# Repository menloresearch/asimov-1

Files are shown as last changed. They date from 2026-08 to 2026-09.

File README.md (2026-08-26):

# Asimov 1: Open-Source Humanoid Robot




Asimov is an open-source humanoid robot that you can build, train and customize.

Asimov v1
<p align="center">
  <a href="https://asimov.inc">Website</a> ·
  <a href="https://manual.asimov.inc">Manual</a> ·
  <a href="https://asimov.inc/diy-kit">DIY Kit</a> ·
  <a href="https://static.asimov.inc/asimov/v1/asimov-v1-20260420.html">3D Model</a> ·
  <a href="https://discord.gg/HzDfGN7kUw">Discord</a> ·
  <a href="https://x.com/asimovinc">X</a> ·
  <a href="https://forum.menlo.ai">Forum</a>
</p>

Asimov 1 is a 1.2 m, 35 kg biped with 25 actuated degrees of freedom. This repository contains the mechanical CAD, electrical CAD, simulation model, and onboard software to build, simulate, and customize Asimov 1.

---

## Specifications

| Spec | Value |
|---|---|
| Height | 1.2 m |
| Weight | 35 kg |
| Degrees of Freedom | 25 actuated |
| Legs | 6 DOF x 2 |
| Arms | 5 DOF x 2 (shoulder pitch/roll/yaw, elbow, wrist yaw) |
| Torso | 1 DOF waist yaw, 10 W 4 ohm speaker, 6 DOF IMU |
| Head | 2 DOF neck (neck yaw, neck pitch), stereo microphone array, 2MP monocular camera |
| CAN Bus | 5 @ 1Mbps + 1 @ 500kbps |
| Onboard Compute | Raspberry Pi 5 (media + network) + Radxa CM5 (motion control) |
| Structural Materials | 7075 aluminium, MJF PA12 nylon |

| Activity | Load |
|---|---|
| Squat | 5 kg |
| Bicep curl | 15 kg each arm |
| Lateral raise | 18 kg each arm |

---

## Build your own Asimov

> [!TIP]
> **Option 1: DIY Kit:** Everything you need to build Asimov 1, unassembled. Shipping now for $20,000. [Order now →](https://menlo.ai/asimov-1#buy)

> [!NOTE]
> **Option 2: Self-source:** Pull the [BOM](https://docs.menlo.ai/asimov/1/assembly-preparations/self-source/select-release-and-bom) and fabricate everything yourself. [Assembly Manual →](https://docs.menlo.ai/asimov/1)

### DIY Kit

| Category | Included | Not Included |
|---|---|---|
| Hardware | All BOM components (unassembled), power supply & cabling, spare parts | Tools, hands |
| Compute | RPi edge board, motion control board, network board, power distribution board | 4G/5G modules |
| Sensors | Monocular camera, IMUs, mic, speaker, motor joint states | Lidar, 360 cam |
| Docs | Quick start guide, manual, DIY build videos | — |

**[Pre-order the Asimov 1 DIY Kit →](https://asimov.inc/diy-kit)**

### Self-source

Start with the repo-local [fabrication manifest](mechanical/FABRICATION_MANIFEST.csv) for the CAD-derived part inventory, then cross-reference the [BOM](https://manual.asimov.inc/v1/bom) and assembly manual for procurement details, sourcing, and fabrication notes.

**[Assembly Manual →](https://manual.asimov.inc)**

---

## Fabrication manifest

The CAD-derived fabrication manifest can be checked locally:

```bash
python3 scripts/generate_fabrication_manifest.py --check
```

---

## Roadmap

| Status | Item |
|---|---|
| ✅ | Mechanical CAD — 7 subassemblies |
| ✅ | MuJoCo simulation model |
| ✅ | Electrical wiring harness |
| ✅ | Electrical schematics & PCB files |
| 🔜 | Asimov Edge |
| 🔜 | Locomotion policy |

---

## Work with us

- **Build questions?**: Ask in the [forum](https://forum.menlo.ai) or open a [GitHub Issue](https://github.com/asimovinc/asimov-v1/issues) for bugs and contributions.
- **Deploying Asimov?**: [Talk to us →](mailto:bd@menlo.ai)
- **Supply chain partner?**: If you manufacture actuators, structural components, or electronics and want to be part of the Asimov supply chain, reach out.
[bd@menlo.ai](mailto:bd@menlo.ai)

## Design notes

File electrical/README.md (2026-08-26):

## Robot Processing Unit 
### Motion Control Board
- The Motion Control Board (MCB) is a carrier board designed for the Radxa CM5. It has an onboard IMU and contains the necessary motor communication buses for the robot to function.
- The Power Distribution Board (PDB) sits on top of the Motion Control Board (MCB) to form the 2 board stackup.

General information:
- Power is supplied via the XT90(2+2) connector on the PDB, with 5V being routed to the MCB at the bottom
- The UART TTL debug lines have been fanned out as test pads on the PDB for debugging purposes.
- The LSM6DSV IMU is located at the bottom of the MCB
- LCSC component IDs are attached in the KiCad source files for direct JLCPCB fabrication and assembly.

### Communication Ports

| Port Type | Quantity | Details |
|---|---|---|
| CAN (SPI-CAN) | 6 | CAN via SPI bridge |
| USB 2.0 | 2 | USB interfaces |
| Ethernet | 1 | 1Gbps |
| I2C | 1 | I2C interface |

### Port Mapping

| Port ID | Purpose |
|---|---|
| LL | Left leg bus |
| RL | Right leg bus |
| LA | Left arm bus |
| RA | Right arm bus |
| NP | Neck pitch connection for the torso bus |
| NY | Neck yaw connection for the torso bus |
| W  | Waist yaw connection for the torso bus |

> Please refer to the KiCAD source files for a detailed view of all pin mappings on the PDB

## Media Unit

The head of the robot contains a RPI5, with 2 boards to support its function.

Head board:
- contains buck converters to power the RPI5 with 5V
- an audio IC to handle the stereo microphones and stereo speakers, although only 1 speaker output is currently used

RPI5 Hat:
- a small hat that allows for a clean 5V connection to the headers of the RPI5
- contains a button, LED and buzzer for basic status messages, similar to a consumer motherboard

## Wiring

- Each line refers to a pre-made cable on the robot
- Certain connections can only be complete post assembly due to space contraints. These connections have been marked with the Joint names WAGO or SOLDER.

> If making cables from scratch, double-check wire pathing to make sure there is sufficient slack on each connection.

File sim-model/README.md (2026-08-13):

# Simulation Model

MuJoCo model for Asimov v1. Floating base with 23 hinge joints, 25 STL link meshes, friction-tuned foot contacts. Built for locomotion policy training and hardware-in-the-loop testing. No actuators are defined in the XML — the training sim configures them in Python.

## Contents

```
sim-model/
├── xmls/asimov_1.xml     Full robot model (MJCF)
├── urdf/asimov_1.urdf    URDF description (shares the same meshes)
└── assets/meshes/        25 STL link meshes
```

## Usage

```bash
python3 -m mujoco.viewer --mjcf=sim-model/xmls/asimov_1.xml
```

Requires [MuJoCo](https://mujoco.org/) 3.x.

## Resources

- [Locomotion Control guide](https://manual.asimov.inc/v1/locomotion) — policy training, control modes, and hardware-in-the-loop setup
- [Asimov API](https://manual.asimov.inc/v1/api) — deploy policies to the real robot
- [Discord](https://discord.gg/HzDfGN7kUw) — questions and discussion

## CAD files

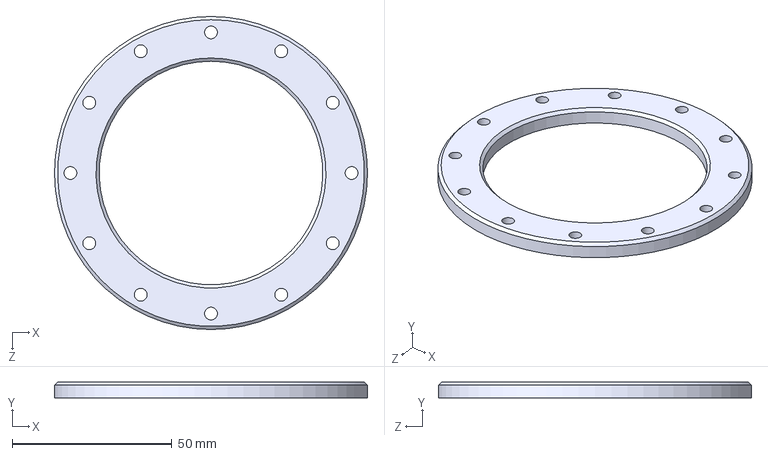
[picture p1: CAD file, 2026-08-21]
mechanical/ASV1/100/FABRICATION/ALU_7075/ASV1_100_08A.STEP
98.0 x 5.00 x 98.0 mm

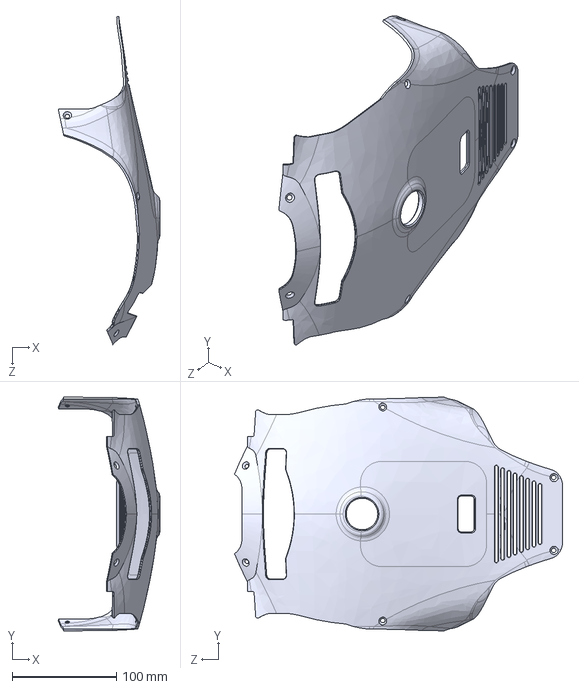
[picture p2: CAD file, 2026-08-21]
mechanical/ASV1/100/FABRICATION/MJF_PA12/ASV1_100_04C.STEP
97.5 x 224.3 x 314.8 mm

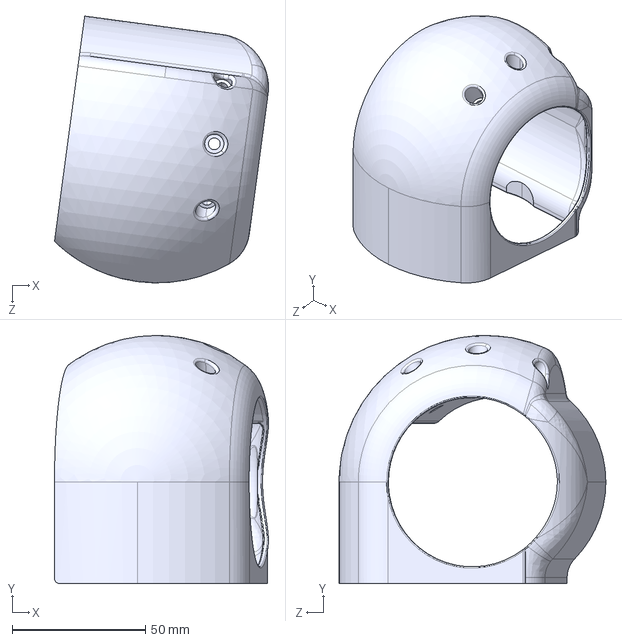
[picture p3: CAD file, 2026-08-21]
mechanical/ASV1/200/FABRICATION/MJF_PA12/ASV1_200_08C.STEP
80.2 x 92.9 x 100.0 mm

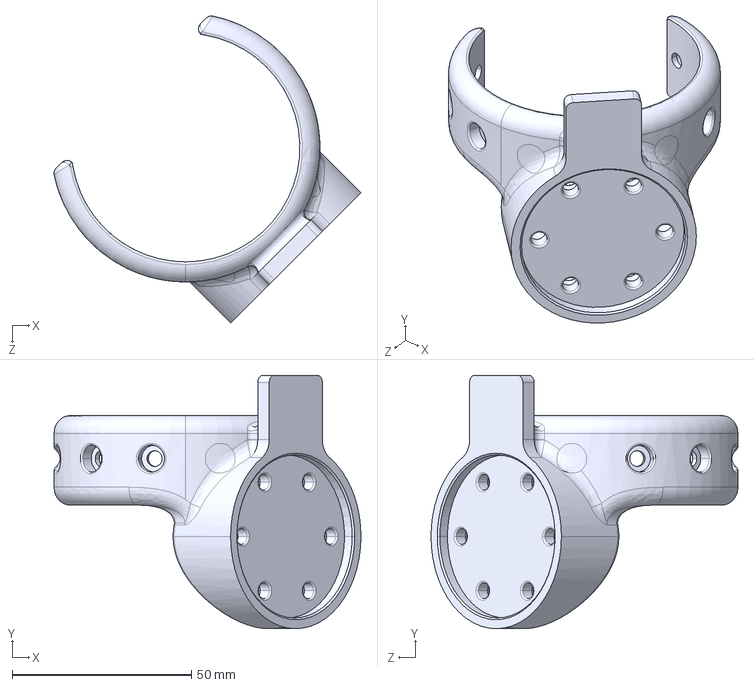
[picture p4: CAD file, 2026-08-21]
mechanical/ASV1/200/FABRICATION/SML_316L/ASV1_200_04B.STEP
85.7 x 70.7 x 85.7 mm

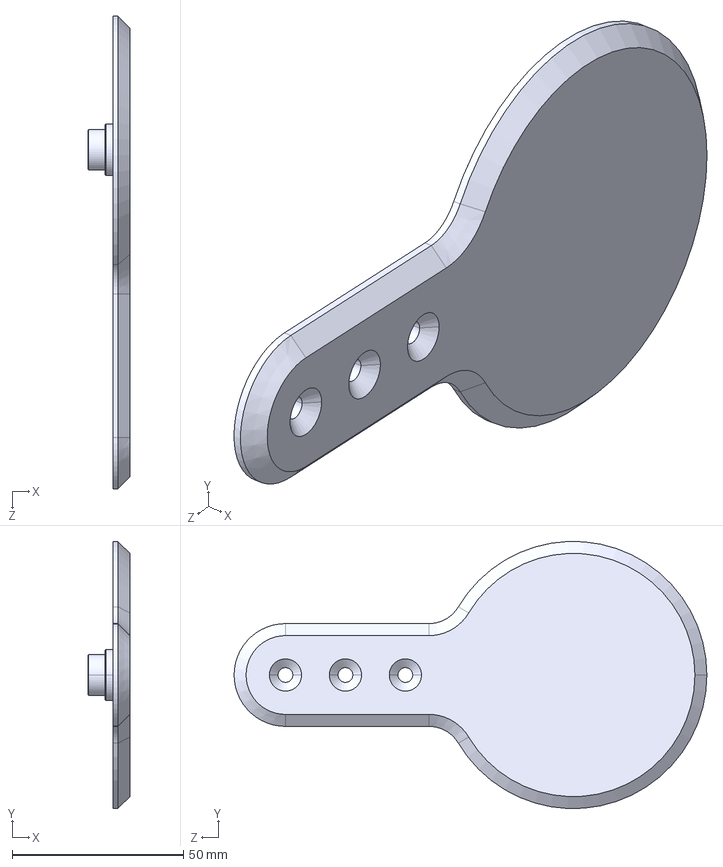
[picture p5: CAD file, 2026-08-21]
mechanical/ASV1/300/FABRICATION/ALU_7075/ASV1_300_10A.STEP
12.2 x 77.9 x 138.0 mm

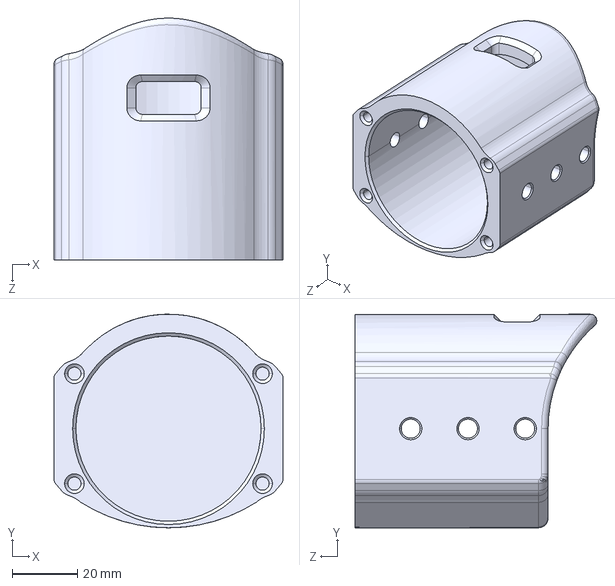
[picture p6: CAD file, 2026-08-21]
mechanical/ASV1/300/FABRICATION/MJF_PA12/ASV1_300_16C.STEP
70.0 x 65.3 x 73.9 mm

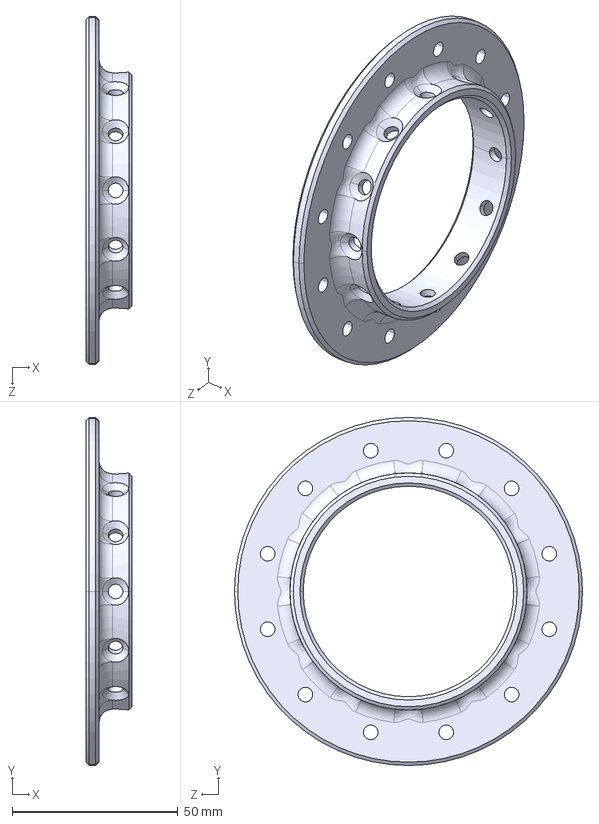
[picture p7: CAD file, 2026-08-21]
mechanical/ASV1/300/FABRICATION/SML_316L/ASV1_300_04B.STEP
14.0 x 105.0 x 105.0 mm

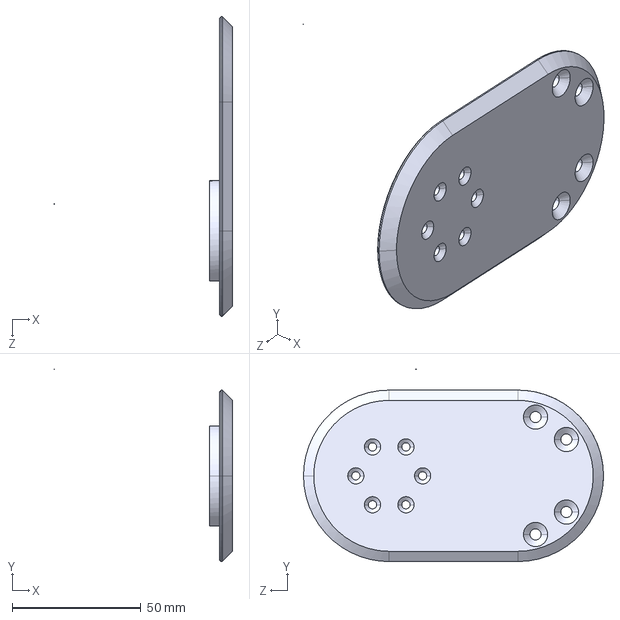
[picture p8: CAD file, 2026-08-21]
mechanical/ASV1/400/FABRICATION/ALU_7075/ASV1_400_01A.STEP
69.3 x 74.8 x 116.7 mm

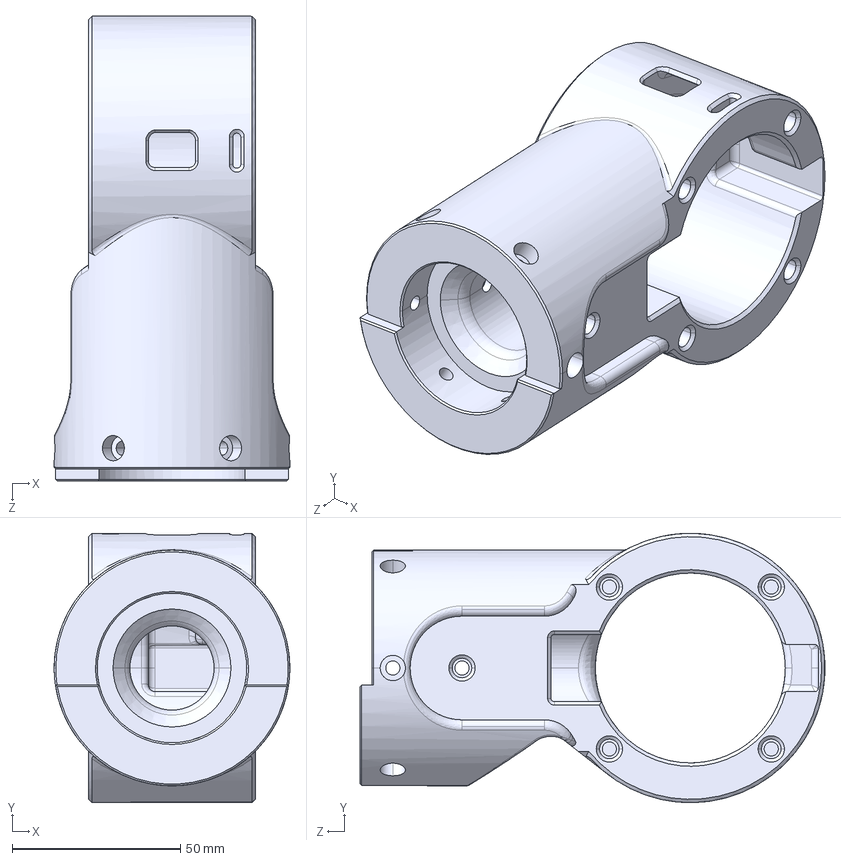
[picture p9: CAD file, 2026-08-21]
mechanical/ASV1/400/FABRICATION/MJF_PA12/ASV1_400_15C.step
70.0 x 80.0 x 138.1 mm

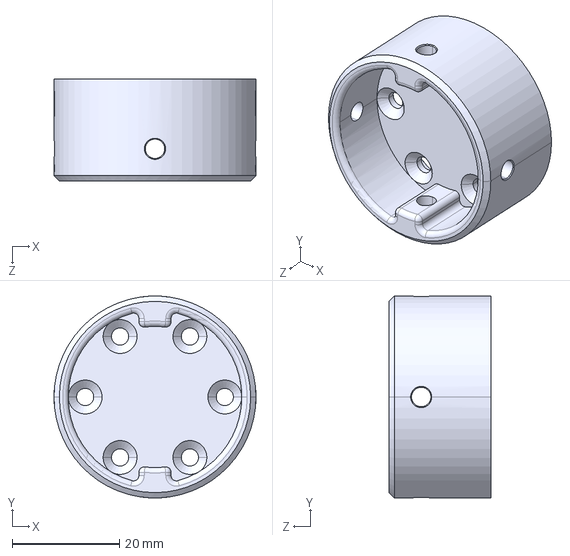
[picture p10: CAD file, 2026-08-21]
mechanical/ASV1/400/FABRICATION/SML_316L/ASV1_400_12B.STEP
37.6 x 37.6 x 19.0 mm

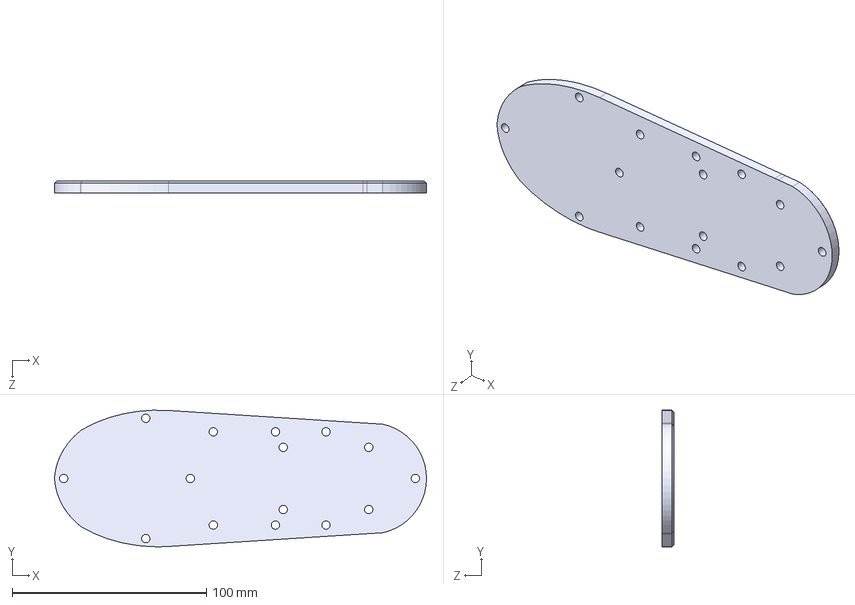
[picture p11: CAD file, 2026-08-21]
mechanical/ASV1/500/FABRICATION/ALU_7075/ASV1_500_36A.STEP
191.5 x 70.3 x 6.00 mm

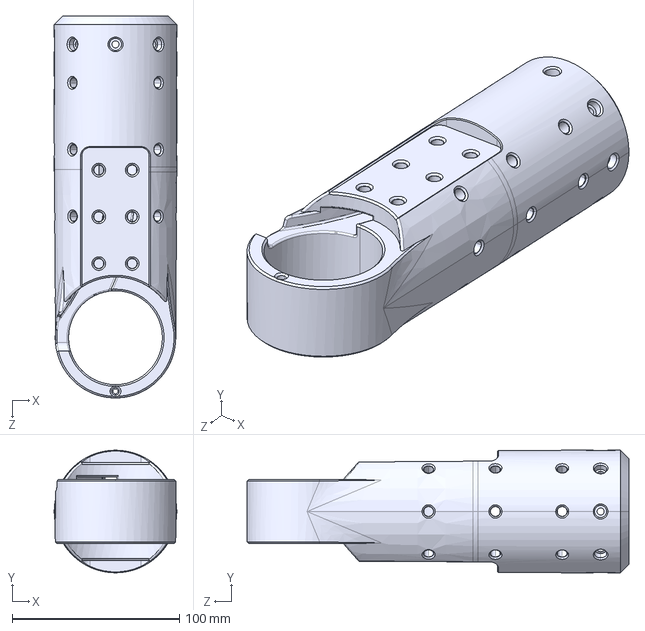
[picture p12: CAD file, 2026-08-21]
mechanical/ASV1/500/FABRICATION/MJF_PA12/ASV1_500_03C.STEP
73.4 x 73.4 x 228.7 mm

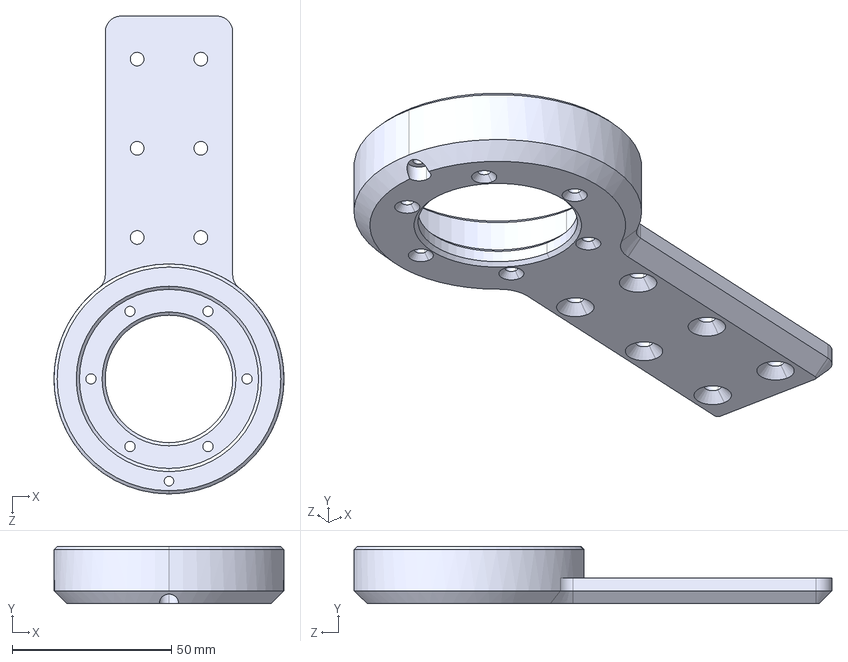
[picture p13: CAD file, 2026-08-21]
mechanical/ASV1/600/FABRICATION/ALU_7075/ASV1_600_06A.STEP
72.2 x 18.0 x 150.0 mm

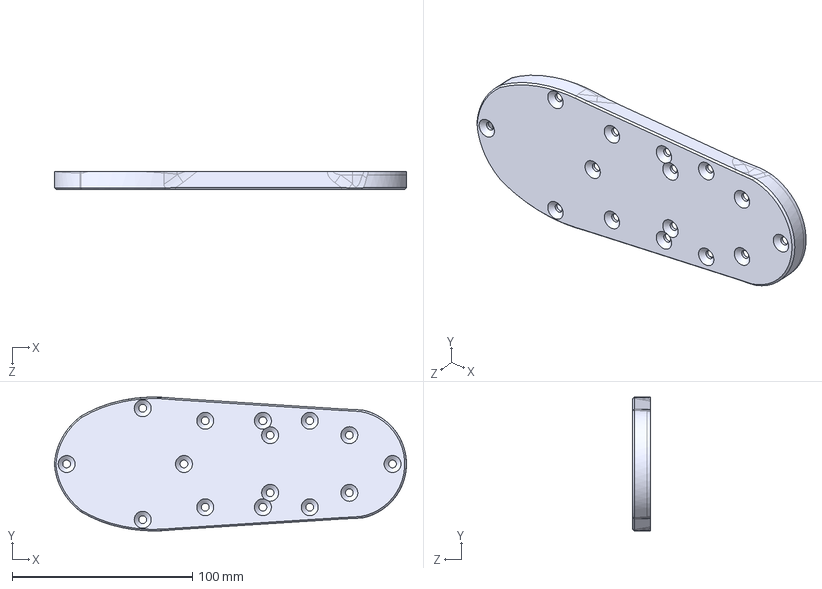
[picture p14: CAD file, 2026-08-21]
mechanical/ASV1/600/FABRICATION/MJF_PA12/ASV1_600_39C.STEP
195.5 x 74.4 x 10.0 mm

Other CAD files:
mechanical/ASV1/600/FABRICATION/SML_316L/ASV1_600_17B.STEP
mechanical/ASV1/700/FABRICATION/MJF_PA12/ASV1_700_06C.STEP
mechanical/ASV1/FullBodyAssembly/Asimov_1.STEP
sim-model/assets/meshes/ANKLE_B_NEW.STL
mechanical/ASV1/100/FABRICATION/MJF_PA12/ASV1_100_12C.STEP
mechanical/ASV1/100/FABRICATION/MJF_PA12/ASV1_100_16C.STEP
mechanical/ASV1/100/FABRICATION/OFF_THE_SHELF/ASV1_100_13X.STEP
mechanical/ASV1/100/FABRICATION/OFF_THE_SHELF/ASV1_100_14X.STEP
mechanical/ASV1/100/FABRICATION/OFF_THE_SHELF/ASV1_100_15X.STEP
mechanical/ASV1/100/FABRICATION/OFF_THE_SHELF/ASV1_100_16X.STEP
mechanical/ASV1/200/FABRICATION/MJF_PA12/ASV1_200_06C.STEP
mechanical/ASV1/200/FABRICATION/MJF_PA12/ASV1_200_15C.STEP
mechanical/ASV1/300/FABRICATION/ALU_7075/ASV1_300_01A.STEP
mechanical/ASV1/300/FABRICATION/ALU_7075/ASV1_300_02A.STEP
mechanical/ASV1/300/FABRICATION/ALU_7075/ASV1_300_03A.STEP
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

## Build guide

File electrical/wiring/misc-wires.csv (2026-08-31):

Joint_1 | Joint_2 | Length (mm) | End_1 | End_2 | Qty
RPU | RPI | 1000 | RJ45 Male | RJ45 Male | 1
RPU | Head Board | 1000 | XT30-F | XT30-M | 1
RPU | Fan | 100 | JST-XH 4 pin | SOLDER | 1
Head Board | RPI 5 Hat | 120 | JST-XH 4 pin | JST-XH 4 pin | 1
Head Board | RPI | 100 | USB-C | USB-A | 1
Head Board | WAGO | 100 | JST-XH 4 pin | N/A | 1
Speaker | WAGO | 200 | SOLDER | N/A | 1

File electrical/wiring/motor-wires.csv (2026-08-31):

Joint_1 | Joint_2 | Length (mm) | End_1 | End_2 | Qty
Left Shoulder Pitch | SOLDER | 180 | XT30F(2+2) | N/A | 1
Left Shoulder Roll | SOLDER | 100 | XT30F(2+2) | N/A | 1
Left Shoulder Roll | Left Shoulder Yaw | 100 | XT30F(2+2) | XT30F(2+2) | 1
Left Shoulder Yaw | WAGO | 180 | XT30F(2+2) | N/A | 1
Left Elbow | WAGO | 100 | XT30F(2+2) | N/A | 1
Left Elbow | Left Wrist Yaw | 230 | XT30F(2+2) | XT30F(2+2) | 1
Right Shoulder Pitch | SOLDER | 180 | XT30F(2+2) | N/A | 1
Right Shoulder Roll | SOLDER | 100 | XT30F(2+2) | N/A | 1
Right Shoulder Roll | Right Shoulder Yaw | 100 | XT30F(2+2) | XT30F(2+2) | 1
Right Shoulder Yaw | WAGO | 180 | XT30F(2+2) | N/A | 1
Right Elbow | WAGO | 100 | XT30F(2+2) | N/A | 1
Right Elbow | Right Wrist Yaw | 230 | XT30F(2+2) | XT30F(2+2) | 1
Left Hip Pitch | Left Hip Roll | 200 | XT30F(2+2) | XT30F(2+2) | 1
Left Hip Roll | SOLDER | 180 | XT30F(2+2) | N/A | 1
Left Hip Yaw | SOLDER | 280 | XT30F(2+2) | N/A | 1
Left Hip Yaw | Left Knee | 150 | XT30F(2+2) | XT30F(2+2) | 1
Left Knee | Left Ankle A | 100 | XT30F(2+2) | XT30F(2+2) | 1
Left Ankle A | Left Ankle B | 100 | XT30F(2+2) | XT30F(2+2) | 1
Right Hip Pitch | Right Hip Roll | 200 | XT30F(2+2) | XT30F(2+2) | 1
Right Hip Roll | SOLDER | 180 | XT30F(2+2) | N/A | 1
Right Hip Yaw | SOLDER | 280 | XT30F(2+2) | N/A | 1
Right Hip Yaw | Right Knee | 150 | XT30F(2+2) | XT30F(2+2) | 1
Right Knee | Right Ankle A | 100 | XT30F(2+2) | XT30F(2+2) | 1
Right Ankle A | Right Ankle B | 100 | XT30F(2+2) | XT30F(2+2) | 1
Neck Yaw | Neck Pitch | 200 | XT30F(2+2) | XT30F(2+2) | 1
RPU | Waist Yaw | 300 | XT30F(2+2) | XT30F(2+2) | 1
RPU | Left Hip Pitch | 300 | XT30F(2+2) | XT30F(2+2) | 1
RPU | Right Hip Pitch | 300 | XT30F(2+2) | XT30F(2+2) | 1
RPU | Left Shoulder Pitch | 400 | XT30F(2+2) | XT30F(2+2) | 1
RPU | Right Shoulder Pitch | 400 | XT30F(2+2) | XT30F(2+2) | 1
RPU | Neck Yaw | 600 | XT30F(2+2) | XT30F(2+2) | 1
RPU | Neck Pitch | 600 | XT30F(2+2) | XT30F(2+2) | 1

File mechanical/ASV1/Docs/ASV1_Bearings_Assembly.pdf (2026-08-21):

D

D

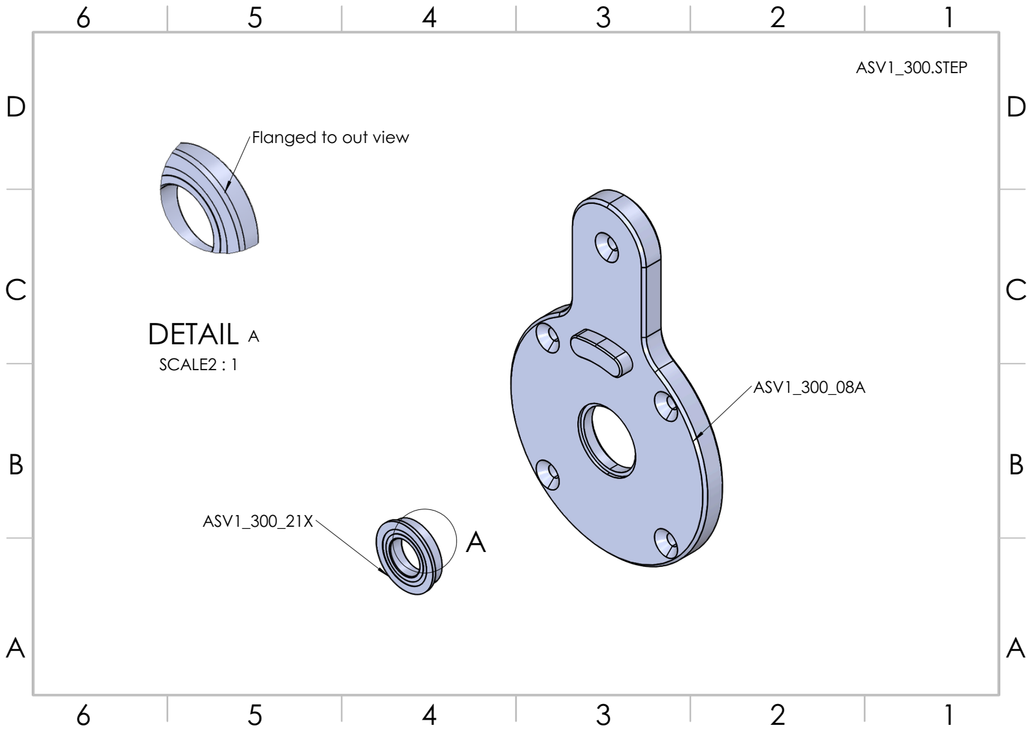
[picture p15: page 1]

# DETAIL

A

A
SCALE2 : 1

ASV1_300_21X

Flanged to out view

ASV1_300_08A

ASV1_300.STEP

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
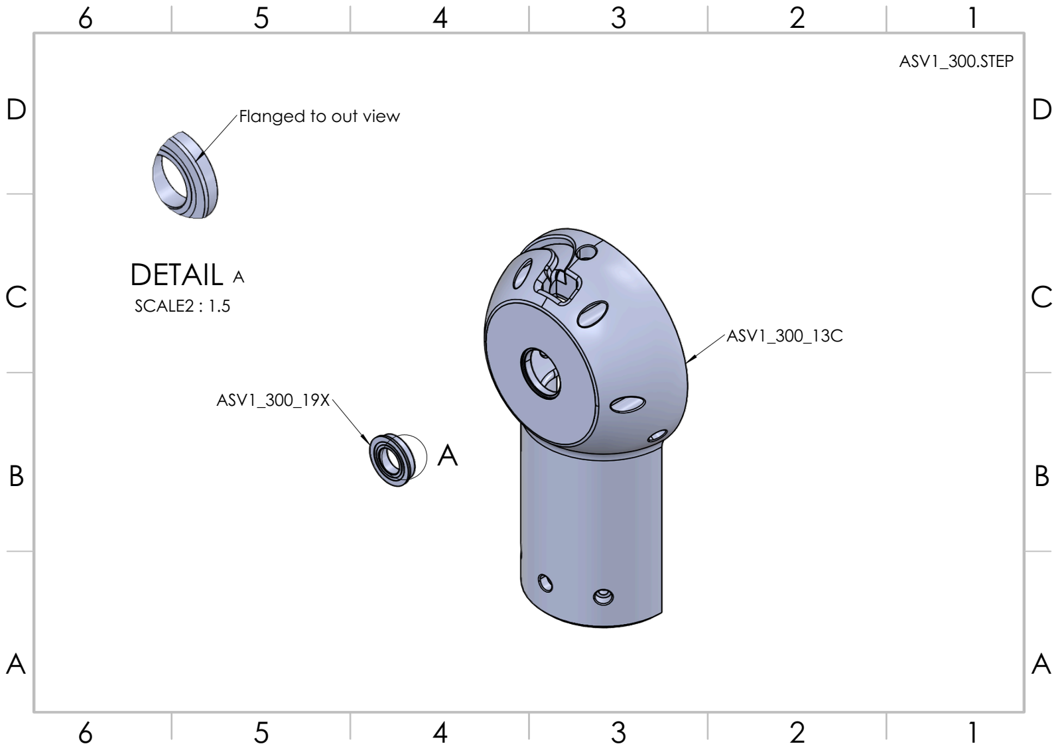
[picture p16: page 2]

# DETAIL

A

A
SCALE2 : 1.5

ASV1_300_19X

Flanged to out view

ASV1_300_13C

ASV1_300.STEP

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
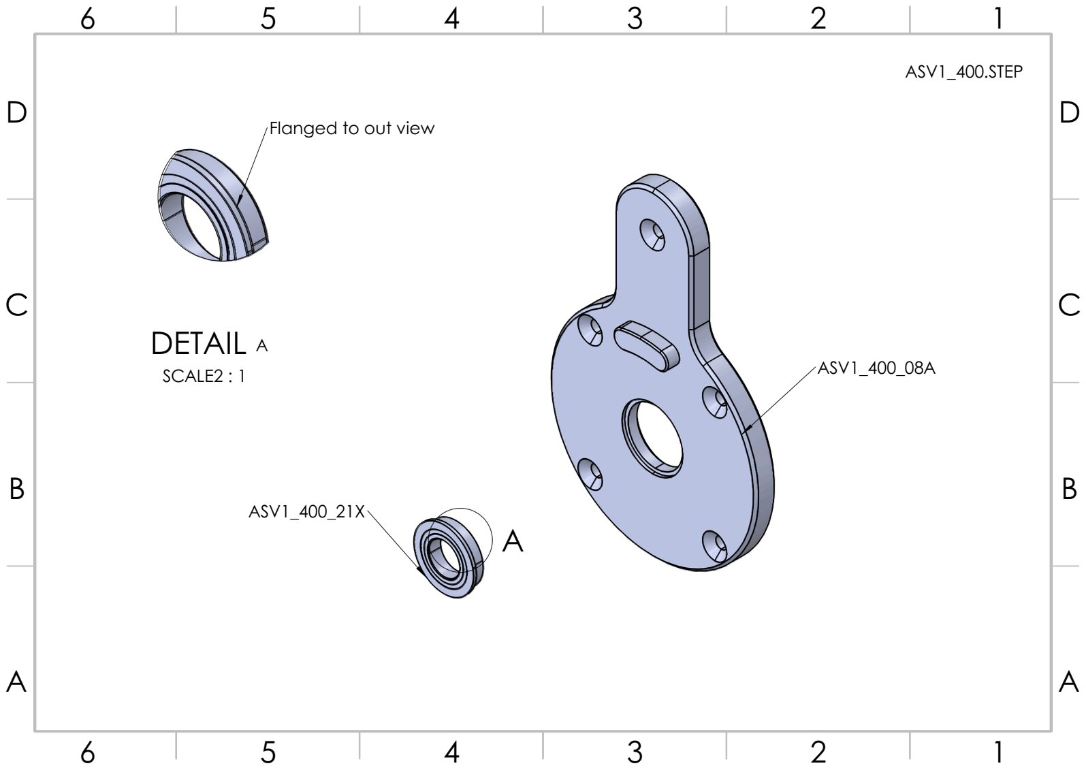
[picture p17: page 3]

# DETAIL

A

A
SCALE2 : 1

ASV1_400_21X

Flanged to out view

ASV1_400_08A

ASV1_400.STEP

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
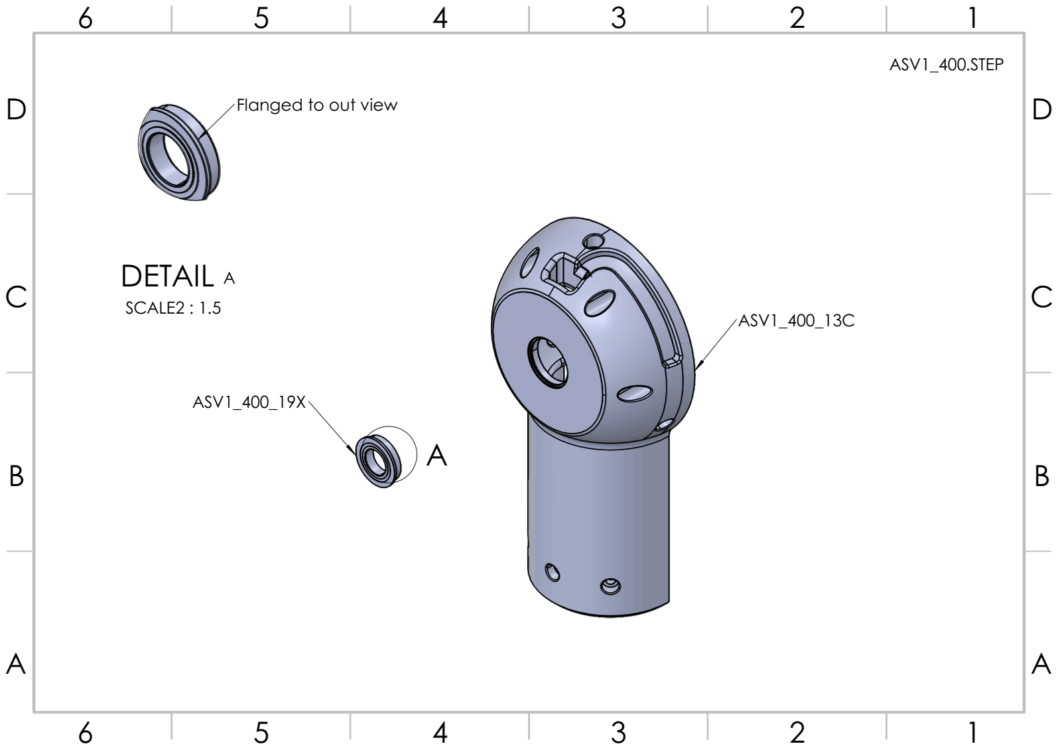
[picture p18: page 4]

# DETAIL

A

A
SCALE2 : 1.5

ASV1_400_19X

Flanged to out view

ASV1_400_13C

ASV1_400.STEP

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
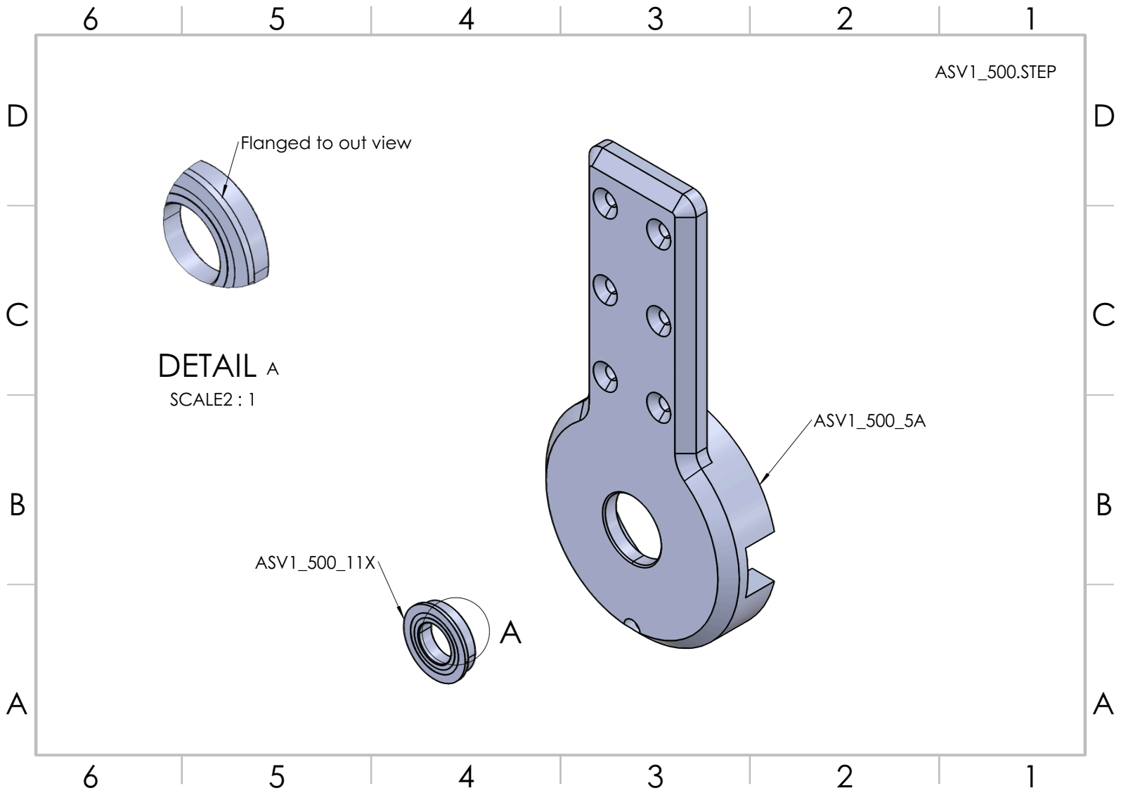
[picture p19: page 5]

# DETAIL

A

A
SCALE2 : 1

ASV1_500_11X

Flanged to out view

ASV1_500_5A

ASV1_500.STEP

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
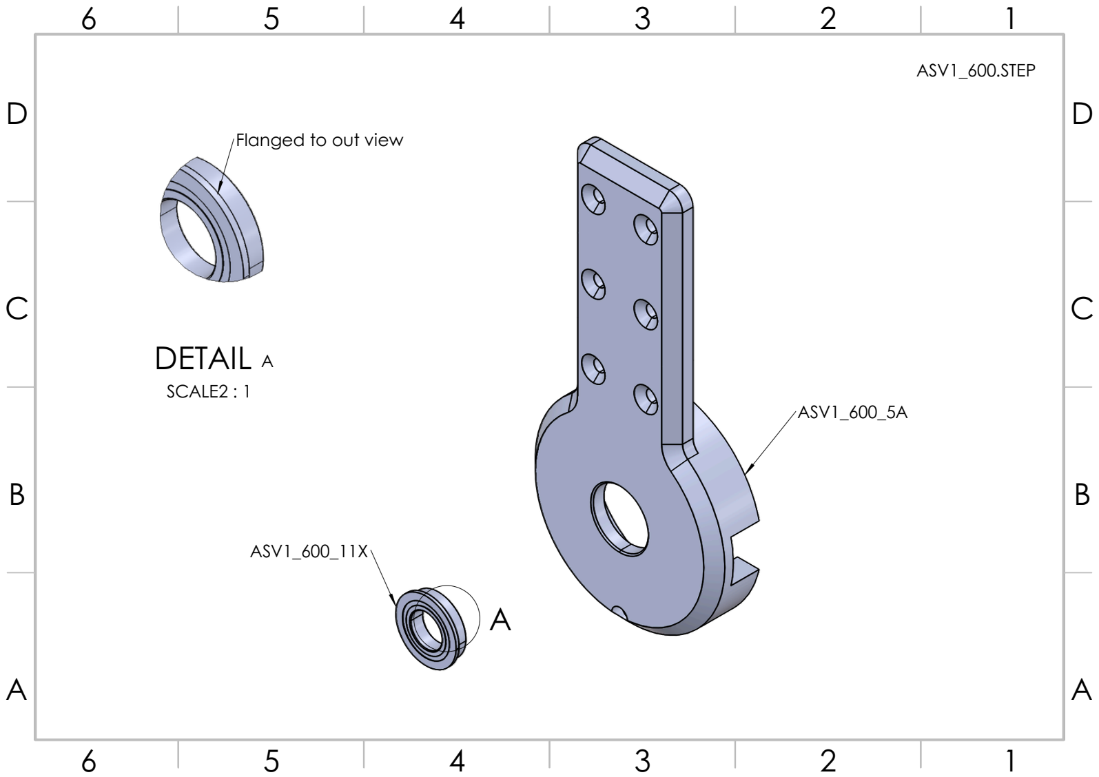
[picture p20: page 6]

# DETAIL

A

A
SCALE2 : 1

ASV1_600_11X

Flanged to out view

ASV1_600_5A

ASV1_600.STEP

C

A

B

C

A

B

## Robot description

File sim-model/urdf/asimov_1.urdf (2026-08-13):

<?xml version="1.0" ?>
<robot name="asimov_1">
  <link name="pelvis_link">
    <inertial>
      <origin xyz="-0.05409183232 -3.482595224e-05 -0.01562551822" rpy="0.1586136416 0.0003031020631 1.564644489"/>
      <mass value="3.506912512"/>
      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
    </inertial>
    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
  </link>
  <link name="left_hip_pitch_link">
    <inertial>
      <origin xyz="0.001728954335 0.03605632625 0.0005692667395" rpy="1.641985992 -0.155733979 1.833607493"/>
      <mass value="1.056301122"/>
      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
    </inertial>
    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
  </link>
  <joint name="left_hip_pitch_joint" type="revolute">
    <origin xyz="-0.052 0.0675 -0.044045" rpy="0 0 0"/>
    <parent link="pelvis_link"/>
    <child link="left_hip_pitch_link"/>
    <axis xyz="0 1 0"/>
    <limit lower="-2.094395" upper="1" effort="45" velocity="12.57"/>
  </joint>
  <link name="left_hip_roll_link">
    <inertial>
      <origin xyz="-0.01155413907 -0.0003348279462 -0.02941018527" rpy="-0.01180745454 0.7190823005 -0.04298463393"/>
      <mass value="0.4143681394"/>
      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
    </inertial>
    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
  </link>
  <joint name="left_hip_roll_joint" type="revolute">
    <origin xyz="0.0422501 0.04000027594 0" rpy="0 0 0"/>
    <parent link="left_hip_pitch_link"/>
    <child link="left_hip_roll_link"/>
    <axis xyz="1 0 0"/>
    <limit lower="-0.785398" upper="0.785398" effort="45" velocity="3.98"/>
  </joint>
  <link name="left_hip_yaw_link">
    <inertial>
      <origin xyz="0.00107948197 -0.00598402495 -0.1208133804" rpy="-0.0179107442 0.05361938077 1.506456195"/>
      <mass value="1.866570164"/>
      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
    </inertial>
    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
  </link>
  <joint name="left_hip_yaw_joint" type="revolute">
    <origin xyz="-0.04225 0.00700892571 -0.05152547875" rpy="0 0 0"/>
    <parent link="left_hip_roll_link"/>
    <child link="left_hip_yaw_link"/>
    <axis xyz="0 0 -1"/>
    <limit lower="-0.785398" upper="0.785398" effort="28" velocity="5.45"/>
  </joint>
  <link name="left_knee_link">
    <inertial>
      <origin xyz="-0.002016493104 7.425481682e-05 -0.09037473617" rpy="0.08663120203 0.01290091604 1.434104957"/>
      <mass value="2.391141511"/>
      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
    </inertial>
    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
  </link>
  <joint name="left_knee_joint" type="revolute">
    <origin xyz="0.001515728659 -0.006573890992 -0.218432673" rpy="0 0 0"/>
    <parent link="left_hip_yaw_link"/>
    <child link="left_knee_link"/>
    <axis xyz="0 1 0"/>
    <limit lower="0" upper="1.5" effort="45" velocity="12.25"/>
  </joint>
  <link name="left_ankle_pitch_link">
    <inertial>
      <origin xyz="-0.001179270406 -3.070191135e-08 -0.006176192354" rpy="0.06265384317 6.376502021e-06 1.570810298"/>
      <mass value="0.2730901194"/>
      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
    </inertial>
    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
  </link>
  <joint name="left_ankle_pitch_joint" type="revolute">
    <origin xyz="-0.001515728659 -0.0004350347189 -0.2723441844" rpy="0 0 0"/>
    <parent link="left_knee_link"/>
    <child link="left_ankle_pitch_link"/>
    <axis xyz="0 1 0"/>
    <limit lower="-0.35" upper="0.35" effort="40" velocity="9.32"/>
  </joint>
  <link name="left_ankle_roll_link">
    <inertial>
      <origin xyz="0.0602 0 -0.0174" rpy="0.005104327522 -1.544931719 3.136469831"/>
      <mass value="0.44468"/>
      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
    </inertial>
    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
  </link>
  <joint name="left_ankle_roll_joint" type="revolute">
    <origin xyz="-0.0015 0 -0.01" rpy="0 0 0"/>
    <parent link="left_ankle_pitch_link"/>
    <child link="left_ankle_roll_link"/>
    <axis xyz="-1 0 0"/>
    <limit lower="-0.1" upper="0.1" effort="17" velocity="9.32"/>
  </joint>
  <link name="right_hip_pitch_link">
    <inertial>
      <origin xyz="0.00172891544 -0.03605607775 0.0005688308451" rpy="1.642012672 0.1558053402 1.307990399"/>
      <mass value="1.056297429"/>
      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
    </inertial>
    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
  </link>
  <joint name="right_hip_pitch_joint" type="revolute">
    <origin xyz="-0.052 -0.0675 -0.044045" rpy="0 0 0"/>
    <parent link="pelvis_link"/>
    <child link="right_hip_pitch_link"/>
    <axis xyz="0 -1 0"/>
    <limit lower="-1" upper="2.094395" effort="45" velocity="12.57"/>
  </joint>
  <link name="right_hip_roll_link">
    <inertial>
      <origin xyz="-0.01154356737 0.0003614587139 -0.02938589083" rpy="0.01678978399 0.7187156143 0.05234867676"/>
      <mass value="0.4148250006"/>
      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
    </inertial>
    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
  </link>
  <joint name="right_hip_roll_joint" type="revolute">
    <origin xyz="0.04225 -0.04 0" rpy="0 0 0"/>
    <parent link="right_hip_pitch_link"/>
    <child link="right_hip_roll_link"/>
    <axis xyz="1 0 0"/>
    <limit lower="-0.785398" upper="0.785398" effort="45" velocity="3.98"/>
  </joint>
  <link name="right_hip_yaw_link">
    <inertial>
      <origin xyz="0.00107595248 0.005405345666 -0.1207438346" rpy="-0.01817894937 -0.05354818335 1.63808934"/>
      <mass value="1.866472204"/>
      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
    </inertial>
    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
  </link>
  <joint name="right_hip_yaw_joint" type="revolute">
    <origin xyz="-0.04225 -0.0064271 -0.051601" rpy="0 0 0"/>
    <parent link="right_hip_roll_link"/>
    <child link="right_hip_yaw_link"/>
    <axis xyz="0 0 -1"/>
    <limit lower="-0.785398" upper="0.785398" effort="28" velocity="5.45"/>
  </joint>
  <link name="right_knee_link">
    <inertial>
      <origin xyz="-0.001975986614 2.029398758e-05 -0.09037458064" rpy="0.08662561469 -0.01291300683 1.707565765"/>
      <mass value="2.391101676"/>
      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
    </inertial>
    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
  </link>
  <joint name="right_knee_joint" type="revolute">
    <origin xyz="0.0015157 0.0059921 -0.21836" rpy="0 0 0"/>
    <parent link="right_hip_yaw_link"/>
    <child link="right_knee_link"/>
    <axis xyz="0 -1 0"/>
    <limit lower="-1.5" upper="0" effort="45" velocity="12.25"/>
  </joint>
  <link name="right_ankle_pitch_link">
    <inertial>
      <origin xyz="-0.00117936926 6.867168649e-08 -0.006176145828" rpy="0.06266784342 -1.065072753e-05 1.570803126"/>
      <mass value="0.2730891716"/>
      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
    </inertial>
    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
  </link>
  <joint name="right_ankle_pitch_joint" type="revolute">
    <origin xyz="-0.0015157 0.00053505 -0.27234" rpy="0 0 0"/>
    <parent link="right_knee_link"/>
    <child link="right_ankle_pitch_link"/>
    <axis xyz="0 -1 0"/>
    <limit lower="-0.35" upper="0.35" effort="40" velocity="9.32"/>
  </joint>
  <link name="right_ankle_roll_link">
    <inertial>
      <origin xyz="0.0602 0 -0.0174" rpy="0.005104327522 -1.544931719 3.136469831"/>
      <mass value="0.44468"/>
      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
    </inertial>
    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
  </link>
  <joint name="right_ankle_roll_joint" type="revolute">
    <origin xyz="-0.0015 0 -0.01" rpy="0 0 0"/>
    <parent link="right_ankle_pitch_link"/>
    <child link="right_ankle_roll_link"/>
    <axis xyz="-1 0 0"/>
    <limit lower="-0.1" upper="0.1" effort="17" velocity="9.32"/>
  </joint>
  <link name="waist_yaw_link">
    <inertial>
      <origin xyz="-0.006993936367 -2.508121256e-05 0.204039878" rpy="-0.0008275530574 -0.1732070005 -0.00249927109"/>
      <mass value="8.208501581"/>
      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
    </inertial>
    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
  </link>
  <joint name="waist_yaw_joint" type="revolute">
    <origin xyz="-0.052 0 0.074755" rpy="0 0 0"/>
    <parent link="pelvis_link"/>
    <child link="waist_yaw_link"/>
    <axis xyz="0 0 1"/>
    <limit lower="-1.570796" upper="1.570796" effort="40" velocity="12.57"/>
  </joint>
  <link name="neck_yaw_link">
    <inertial>
      <origin xyz="-0.0002321550494 -0.0006869323888 0.03567468417" rpy="-1.762751316e-06 -0.185303133 0"/>
      <mass value="0.5327893053"/>
      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
    </inertial>
    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
  </link>
  <joint name="neck_yaw_link_fixed" type="fixed">
    <origin xyz="-0.01659877455 0 0.3781670296" rpy="0 0 0"/>
    <parent link="waist_yaw_link"/>
    <child link="neck_yaw_link"/>
  </joint>
  <link name="neck_pitch_link">
    <inertial>
      <origin xyz="0.01238877547 0.0008619521156 0.04251892729" rpy="2.094949203 0.001222763698 1.57038861"/>
      <mass value="0.3940556092"/>
      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
    </inertial>
    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
  </link>
  <joint name="neck_pitch_link_fixed" type="fixed">
    <origin xyz="0 0 0.03735" rpy="0 0 0"/>
    <parent link="neck_yaw_link"/>
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

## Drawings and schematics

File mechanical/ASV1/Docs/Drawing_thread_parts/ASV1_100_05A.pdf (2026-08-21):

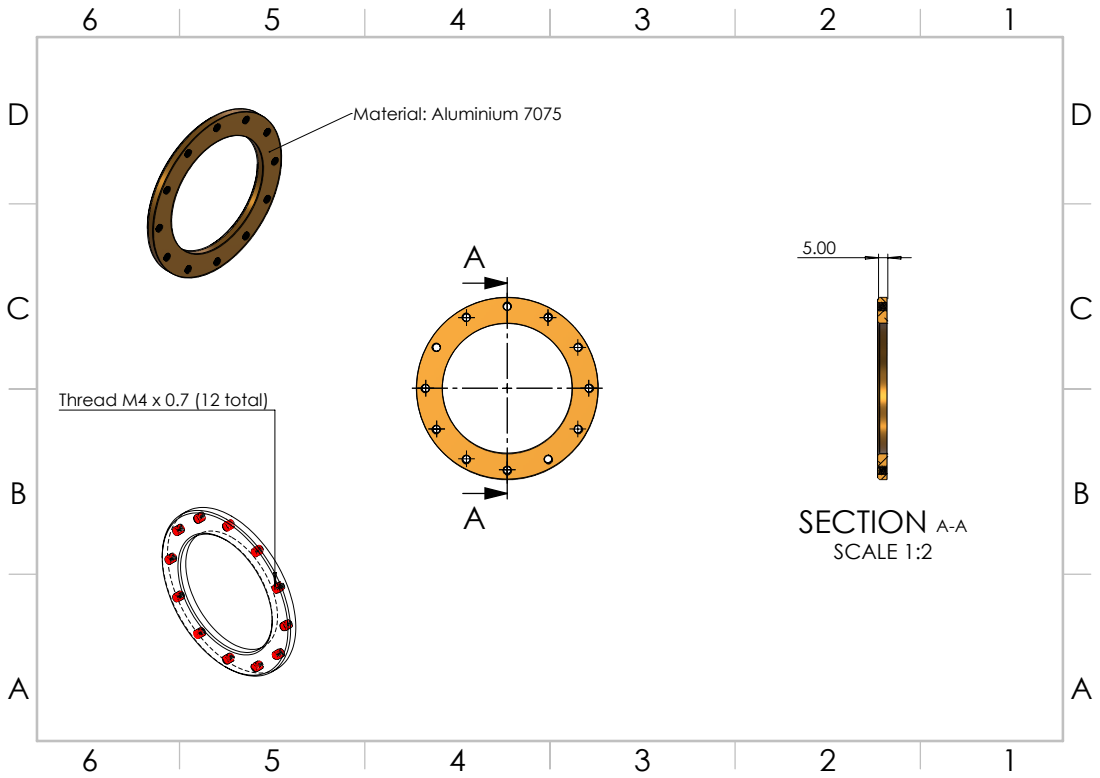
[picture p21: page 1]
Thread M4 x 0.7 (12 total); SECTION A-A SCALE 1:2; Material: Aluminium 7075

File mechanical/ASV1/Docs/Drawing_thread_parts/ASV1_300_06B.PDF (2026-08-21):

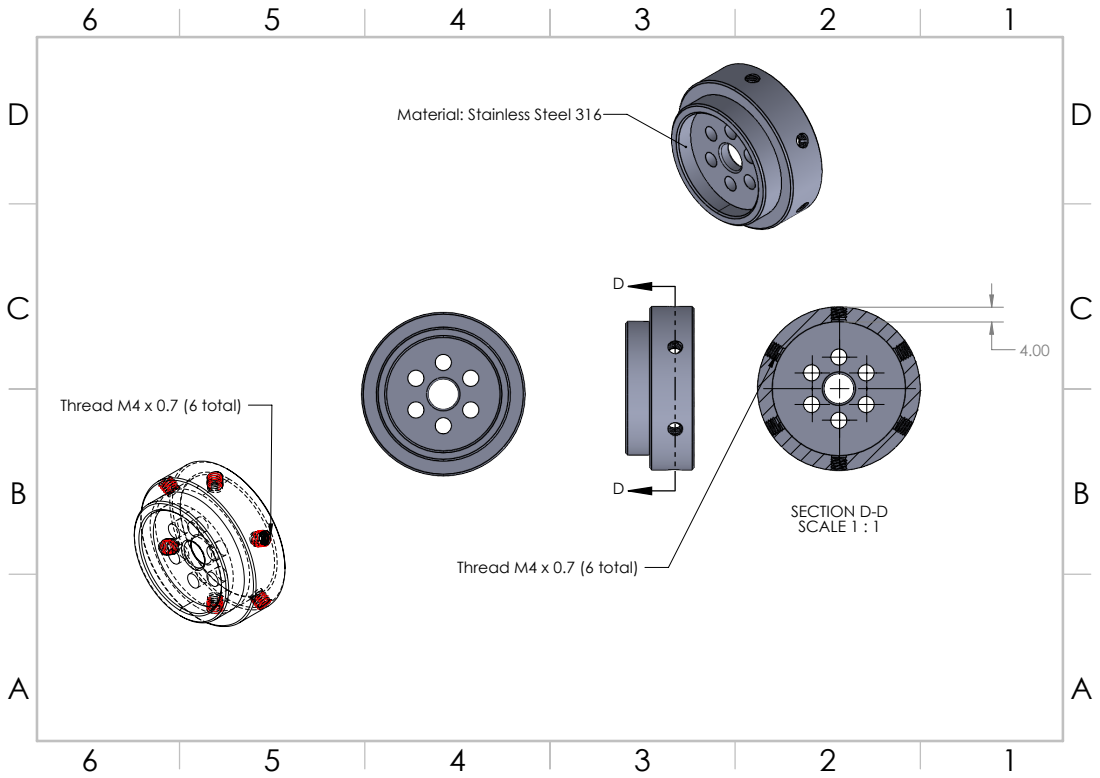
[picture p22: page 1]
Thread M4 x 0.7 (6 total); SECTION D-D SCALE 1 : 1

Material: Stainless Steel 316

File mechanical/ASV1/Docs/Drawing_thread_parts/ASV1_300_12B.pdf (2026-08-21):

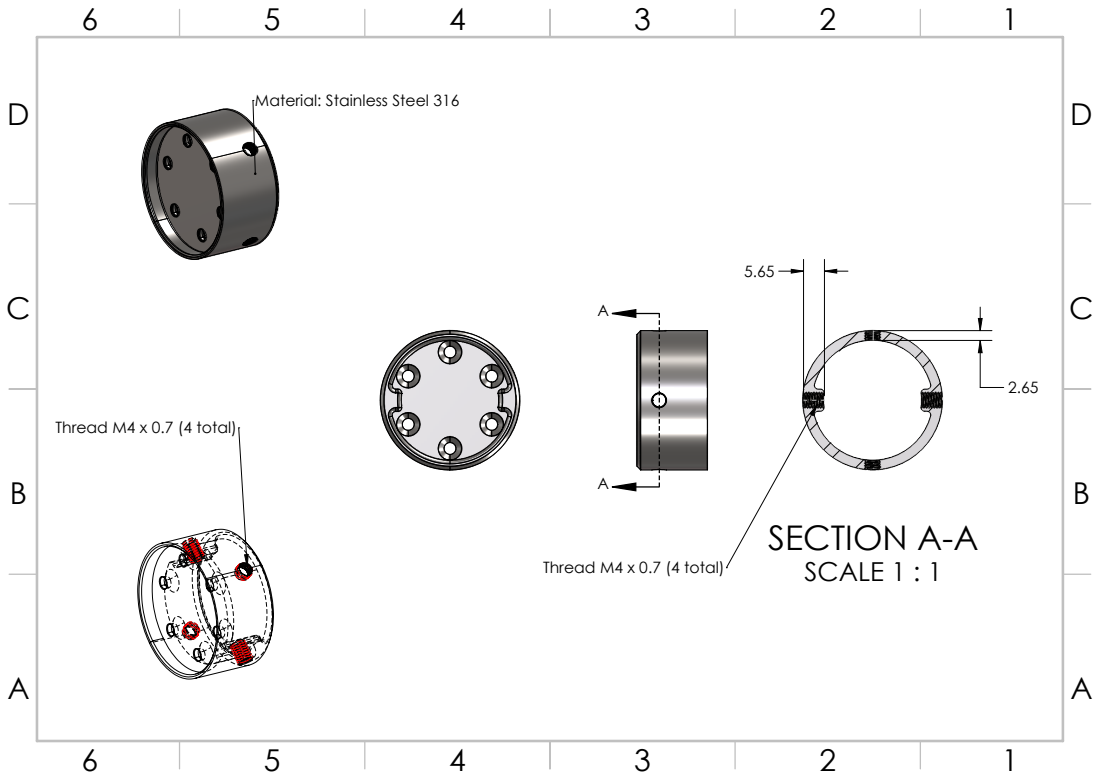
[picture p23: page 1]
SECTION A-A SCALE 1 : 1; Thread M4 x 0.7 (4 total)

Material: Stainless Steel 316

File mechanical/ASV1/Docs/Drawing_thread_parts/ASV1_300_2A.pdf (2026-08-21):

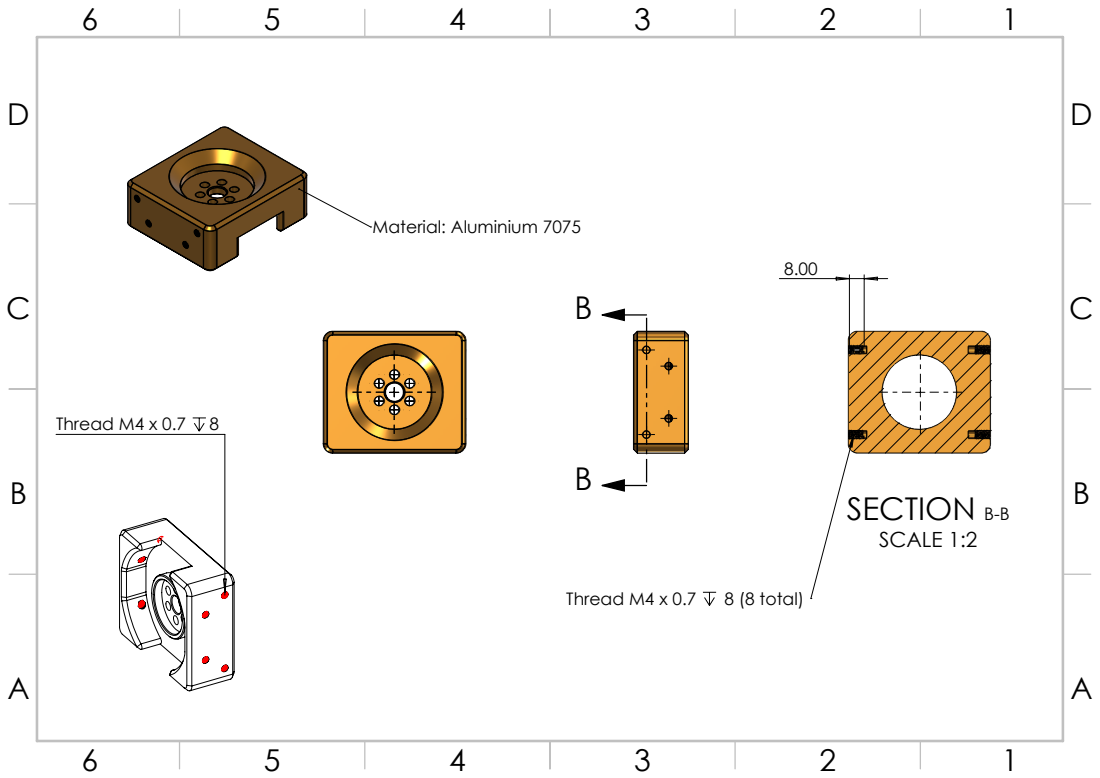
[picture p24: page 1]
Thread M4 x 0.7 8; SECTION B-B SCALE 1:2; Thread M4 x 0.7 8 (8 total); Material: Aluminium 7075

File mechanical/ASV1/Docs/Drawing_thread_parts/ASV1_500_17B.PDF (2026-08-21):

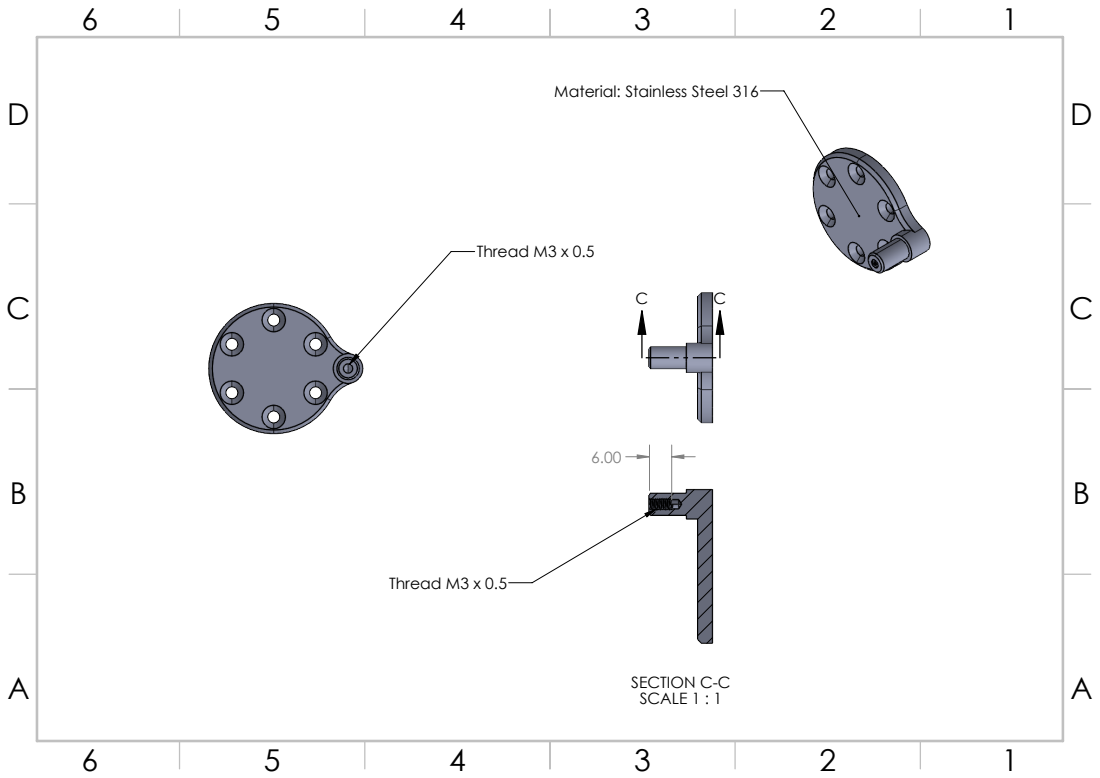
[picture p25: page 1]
Thread M3 x 0.5; SECTION C-C SCALE 1 : 1

Material: Stainless Steel 316

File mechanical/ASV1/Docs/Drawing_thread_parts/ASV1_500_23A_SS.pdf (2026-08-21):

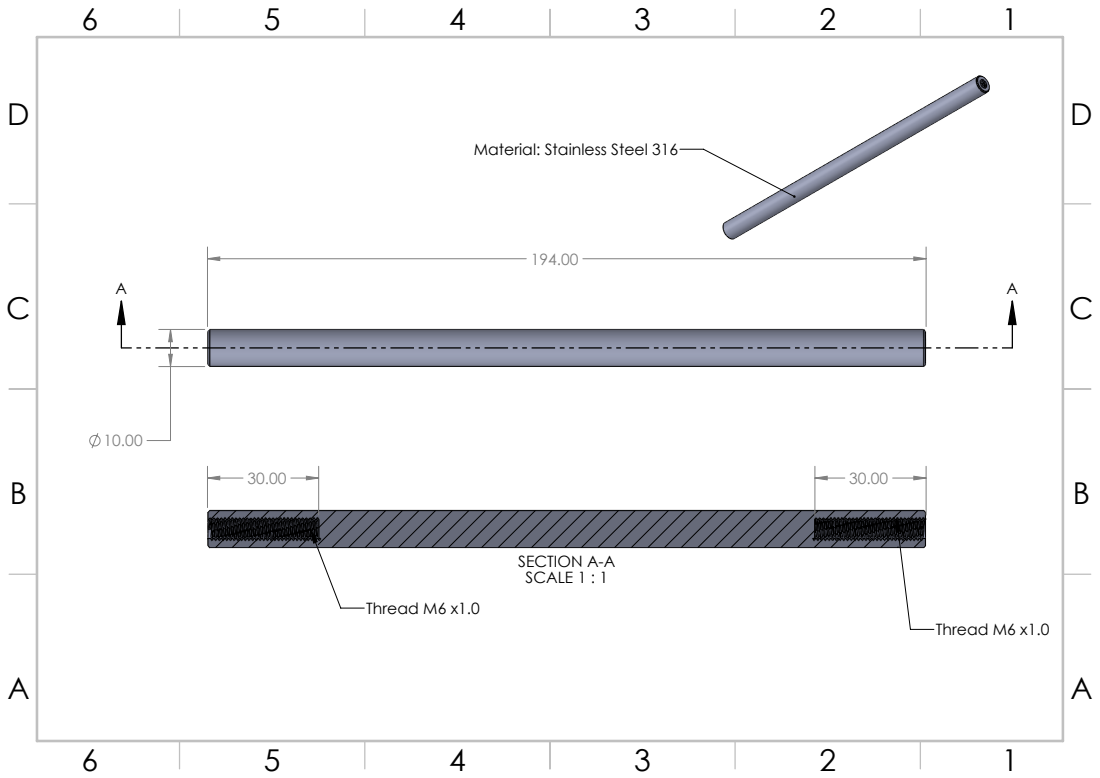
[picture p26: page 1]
SECTION A-A SCALE 1 : 1; Thread M6 x1.0

Material: Stainless Steel 316

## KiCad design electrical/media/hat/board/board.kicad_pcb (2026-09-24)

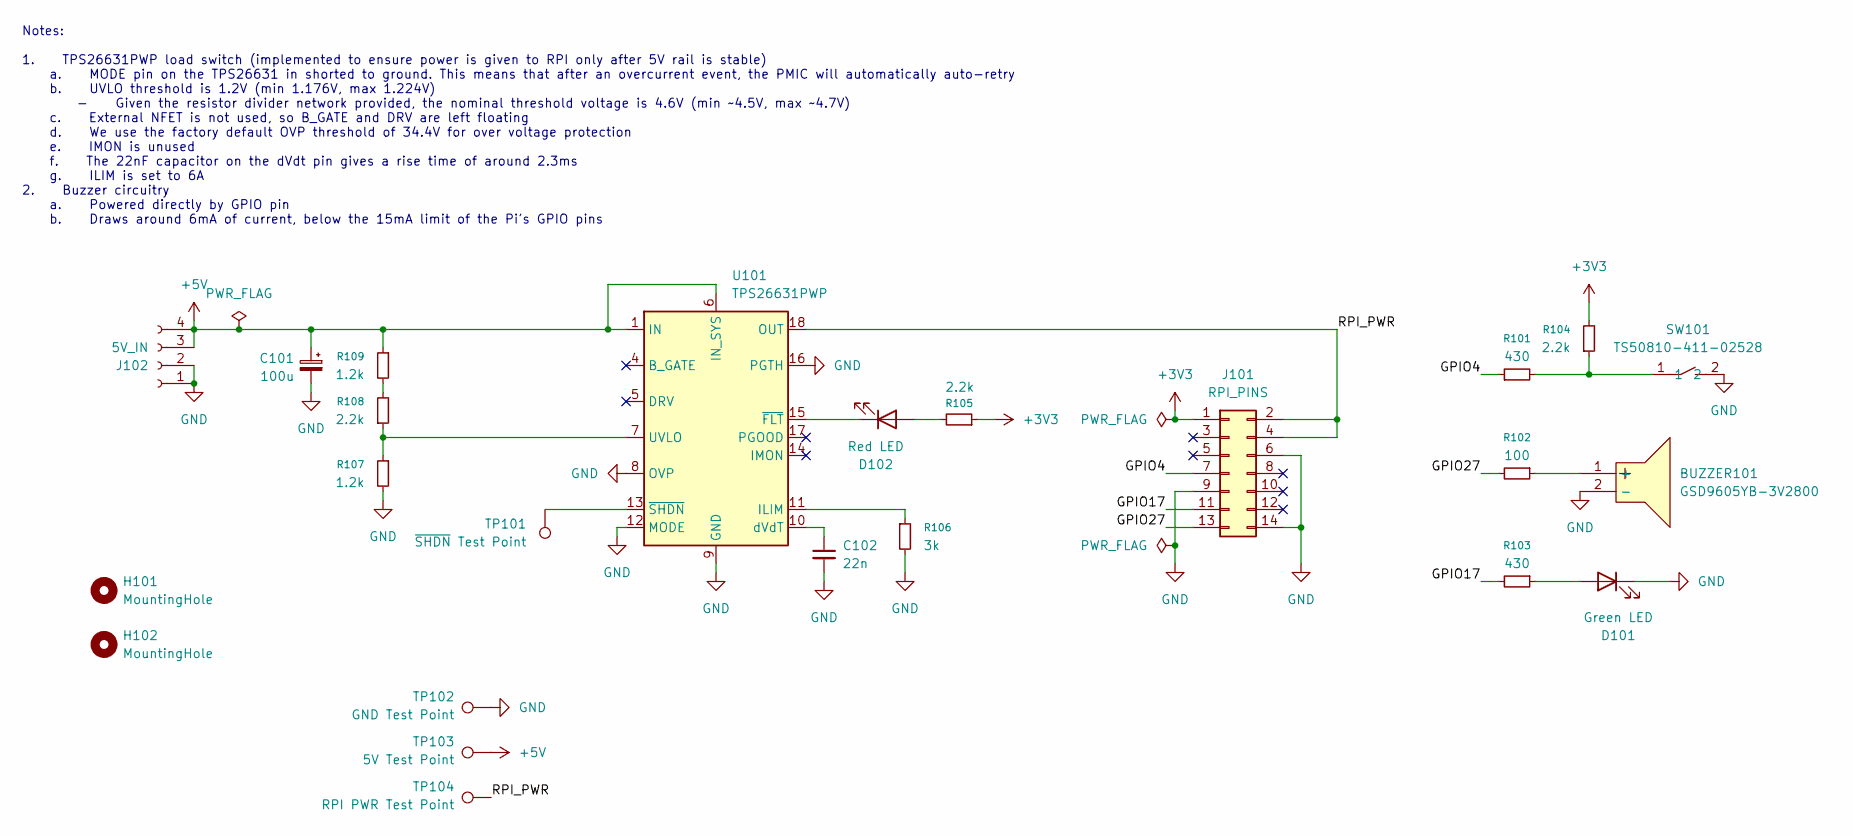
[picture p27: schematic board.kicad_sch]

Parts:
BUZZER101: GSD9605YB-3V2800; BUZ-SMD_GSD9605YB-3V2800; MPN GSD9605YB-3V2800; LCSC Part C255327
C101: 100u; CP_EIA-7343-31_Kemet-D; LCSC C600555
C102: 22n; C_0402_1005Metric; LCSC C1532
D101: Green LED; LED_0603_1608Metric; LCSC C965804
D102: Red LED; LED_0603_1608Metric; LCSC C2286
H101, H102: MountingHole; MountingHole_2.5mm
J101: RPI_PINS; PinSocket_2x07_P2.54mm_Vertical; LCSC C5116484
J102: 5V_IN; JST_XH_B4B-XH-A_1x04_P2.50mm_Vertical; LCSC C144395
R101, R103: 430; R_0402_1005Metric; LCSC C137868
R102: 100; R_0402_1005Metric; LCSC C25076
R104, R105, R108: 2.2k; R_0402_1005Metric; LCSC C25879
R106: 3k; R_0603_1608Metric; LCSC C4211
R107, R109: 1.2k; R_0402_1005Metric; LCSC C2909307
SW101: TS50810-411-02528; SW-SMD_L6.2-W3.7-LS8.0; MPN TS50810-411-02528; LCSC Part C42400876
TP101: ~{SHDN} Test Point; TestPoint_Keystone_5015_Micro_Mini; LCSC C5199798
TP102: GND Test Point; TestPoint_Keystone_5015_Micro_Mini; LCSC C5199798
TP103: 5V Test Point; TestPoint_Keystone_5015_Micro_Mini; LCSC C5199798
TP104: RPI PWR Test Point; TestPoint_Keystone_5015_Micro_Mini; LCSC C5199798
U101: TPS26631PWP; HTSSOP-20-1EP_4.4x6.5mm_P0.65mm_EP3.4x6.5mm_Mask2.96x2.96mm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; LCSC C2866319

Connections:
+3V3: J101.1, R104.2, R105.1
+5V: C101.1, J102.3, J102.4, R109.1, TP103.1 (1_1), U101.1 (IN), U101.2 (IN), U101.3 (IN), U101.6 (IN_SYS)
/GPIO4: J101.7, R101.1
/GPIO17: J101.11, R103.2
/GPIO27: J101.13, R102.2
/RPI_PWR: J101.2, J101.4, TP104.1 (1_1), U101.18 (OUT), U101.19 (OUT), U101.20 (OUT)
GND: BUZZER101.2 (-), C101.2, C102.2, D101.1 (K), J101.6, J101.9, J101.14, J102.1, J102.2, R106.2, R107.2, SW101.2, TP102.1 (1_1), U101.8 (OVP), U101.9 (GND), U101.12 (MODE), U101.16 (PGTH), U101.21 (GND)
unnamed: BUZZER101.1 (+), R102.1
unnamed: D101.2 (A), R103.1
unnamed: D102.2 (A), R105.2
unnamed: D102.1 (K), U101.15 (~FLT)
unnamed: R101.2, R104.1, SW101.1
unnamed: R108.2, R109.2
unnamed: R106.1, U101.11 (ILIM)
unnamed: R107.1, R108.1, U101.7 (UVLO)
unnamed: C102.1, U101.10 (dVdT)
unnamed: TP101.1 (1_1), U101.13 (~SHDN)

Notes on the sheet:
Notes: 1. TPS26631PWP load switch (implemented to ensure power is given to RPI only after 5V rail is stable) a. MODE pin on the TPS26631 in shorted to ground. This means that after an overcurrent event, the PMIC will automatically auto-retry b. UVLO threshold is 1.2V (min 1.176V, max 1.224V) - Give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

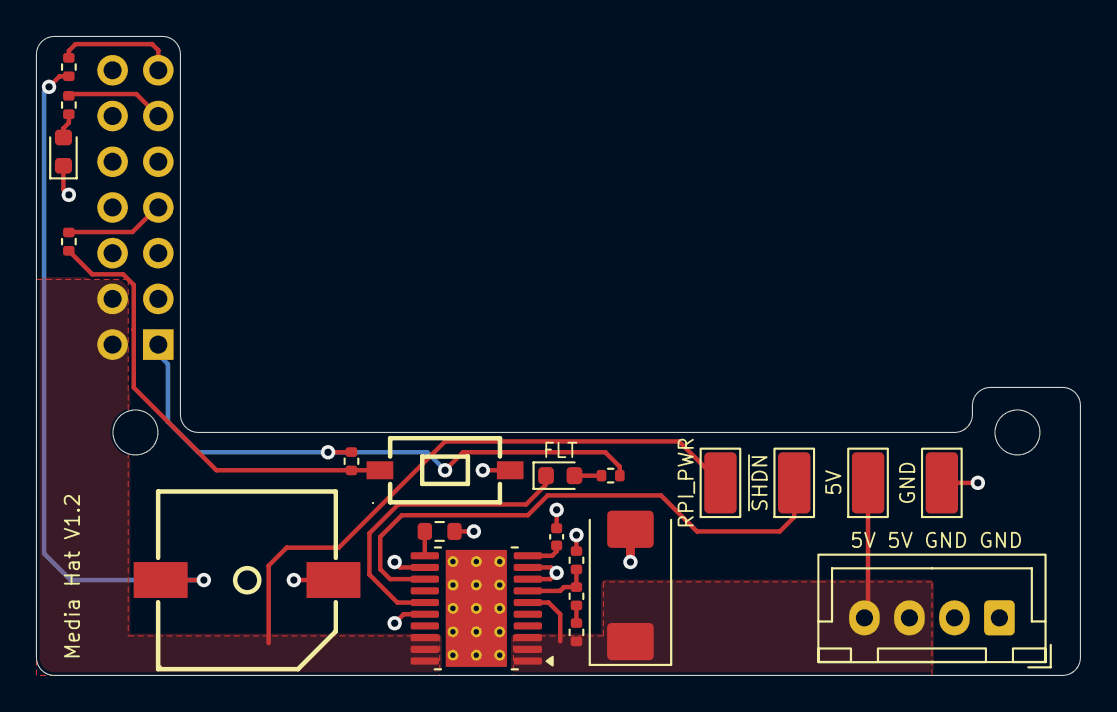
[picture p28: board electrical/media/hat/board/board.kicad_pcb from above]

Board: 2 copper layers, 58.0 x 35.5 mm, 24 parts (1 on the bottom side), 17 nets.

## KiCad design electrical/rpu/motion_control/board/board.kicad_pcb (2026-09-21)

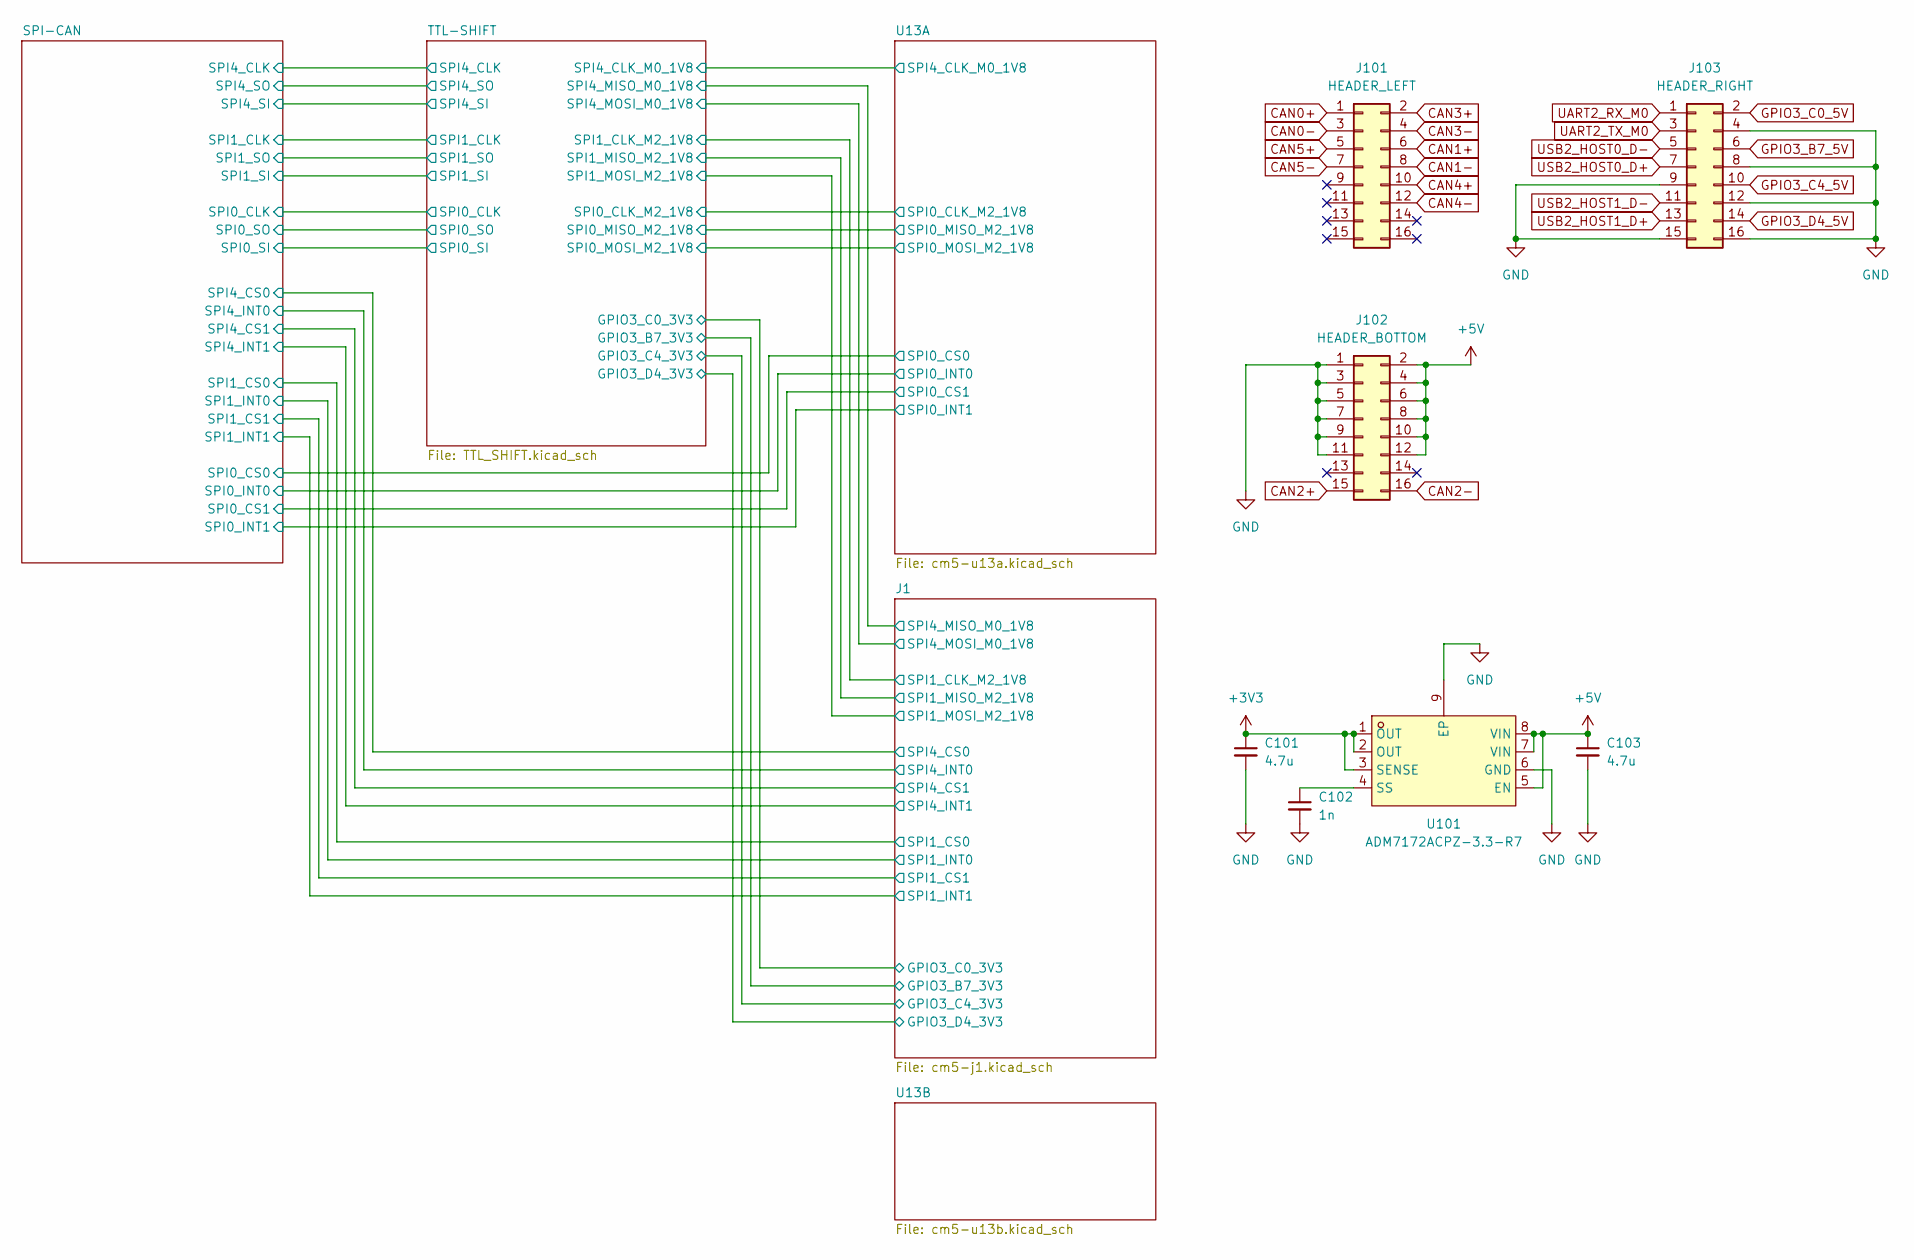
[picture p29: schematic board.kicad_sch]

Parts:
C101, C103: 4.7u; C_0402_1005Metric; LCSC C368809
C102: 1n; C_0402_1005Metric; LCSC C76947
J101: HEADER_LEFT; PinHeader_2x08_P2.54mm_Vertical; LCSC C492425
J102: HEADER_BOTTOM; PinHeader_2x08_P2.54mm_Vertical; LCSC C492425
J103: HEADER_RIGHT; PinHeader_2x08_P2.54mm_Vertical; LCSC C492425
U101: ADM7172ACPZ-3.3-R7; DFN-8_L3.0-W3.0-P0.50-BL-EP; MPN ADM7172ACPZ-3.3-R7; LCSC Part C514342

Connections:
+3V3: C101.1, U101.1 (OUT), U101.2 (OUT), U101.3 (SENSE); also elsewhere on the board
+5V: C103.1, J102.2, J102.4, J102.6, J102.8, J102.10, J102.12, U101.5 (EN), U101.7 (VIN), U101.8 (VIN); also elsewhere on the board
CAN0+: J101.1; also elsewhere on the board
CAN0-: J101.3; also elsewhere on the board
CAN1+: J101.6; also elsewhere on the board
CAN1-: J101.8; also elsewhere on the board
CAN2+: J102.15; also elsewhere on the board
CAN2-: J102.16; also elsewhere on the board
CAN3+: J101.2; also elsewhere on the board
CAN3-: J101.4; also elsewhere on the board
CAN4+: J101.10; also elsewhere on the board
CAN4-: J101.12; also elsewhere on the board
CAN5+: J101.5; also elsewhere on the board
CAN5-: J101.7; also elsewhere on the board
GND: C101.2, C102.2, C103.2, J102.1, J102.3, J102.5, J102.7, J102.9, J102.11, J103.4, J103.8, J103.9, J103.12, J103.15, J103.16, U101.6 (GND), U101.9 (EP); also elsewhere on the board
GPIO3_B7_5V: J103.6; also elsewhere on the board
GPIO3_C0_5V: J103.2; also elsewhere on the board
GPIO3_C4_5V: J103.10; also elsewhere on the board
GPIO3_D4_5V: J103.14; also elsewhere on the board
unnamed: C102.1, U101.4 (SS)
UART2_RX_M0: J103.1; also elsewhere on the board
UART2_TX_M0: J103.3; also elsewhere on the board
USB2_HOST0_D+: J103.7; also elsewhere on the board
USB2_HOST0_D-: J103.5; also elsewhere on the board
USB2_HOST1_D+: J103.13; also elsewhere on the board
USB2_HOST1_D-: J103.11; also elsewhere on the board

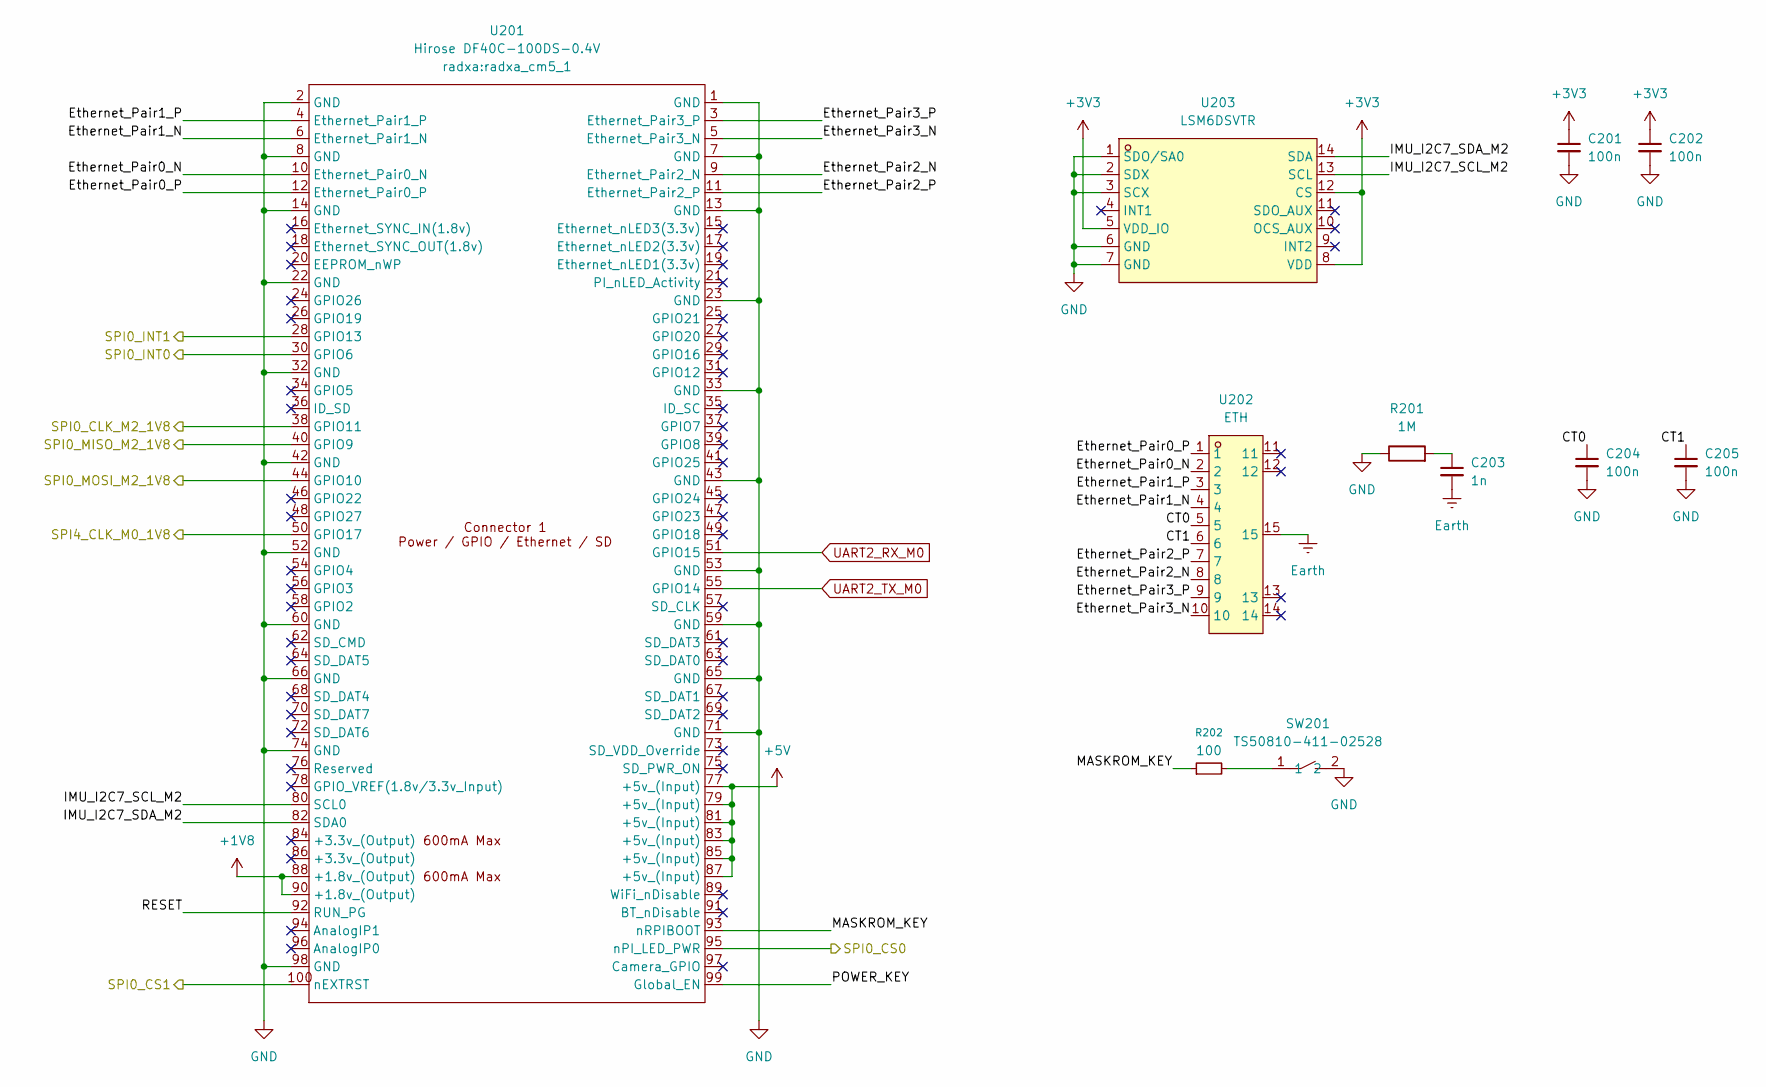
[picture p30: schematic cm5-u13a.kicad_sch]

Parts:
C201, C202: 100n; C_0402_1005Metric; LCSC C77020
C203: 1n; C_1206_3216Metric; LCSC C23631
C204, C205: 100n; C_0402_1005Metric; LCSC C541464
R201: 1M; R_2010_5025Metric; LCSC C1513439
R202: 100; R_0402_1005Metric; LCSC C106232
SW201: TS50810-411-02528; SW-SMD_L6.2-W3.7-LS8.0; MPN TS50810-411-02528; LCSC Part C42400876
U201: Hirose DF40C-100DS-0.4V; radxa_cm5_1; LCSC C597931
U202: ETH; RJ45-SMD_HR963380AE; MPN HR963380AE; LCSC Part C19724763
U203: LSM6DSVTR; LGA-14_L3.0-W2.5-P0.50-TL; LCSC Part C5267399

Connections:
+1V8: U201.88 (+1.8v_(Output)), U201.90 (+1.8v_(Output)); also elsewhere on the board
+3V3: C201.1, C202.1, U203.5 (VDD_IO), U203.8 (VDD), U203.12 (CS); also elsewhere on the board
+5V: U201.77 (+5v_(Input)), U201.79 (+5v_(Input)), U201.81 (+5v_(Input)), U201.83 (+5v_(Input)), U201.85 (+5v_(Input)), U201.87 (+5v_(Input)); also elsewhere on the board
/SPI-CAN/SPI0_CS0: U201.95 (nPI_LED_PWR); also elsewhere on the board
/SPI-CAN/SPI0_CS1: U201.100 (nEXTRST); also elsewhere on the board
/SPI-CAN/SPI0_INT0: U201.30 (GPIO6); also elsewhere on the board
/SPI-CAN/SPI0_INT1: U201.28 (GPIO13); also elsewhere on the board
/TTL-SHIFT/SPI0_CLK_M2_1V8: U201.38 (GPIO11); also elsewhere on the board
/TTL-SHIFT/SPI0_MISO_M2_1V8: U201.40 (GPIO9); also elsewhere on the board
/TTL-SHIFT/SPI0_MOSI_M2_1V8: U201.44 (GPIO10); also elsewhere on the board
/TTL-SHIFT/SPI4_CLK_M0_1V8: U201.50 (GPIO17); also elsewhere on the board
/U13A/CT0: C204.1, U202.5
/U13A/CT1: C205.1, U202.6
/U13A/Ethernet_Pair0_N: U201.10 (Ethernet_Pair0_N), U202.2
/U13A/Ethernet_Pair0_P: U201.12 (Ethernet_Pair0_P), U202.1
/U13A/Ethernet_Pair1_N: U201.6 (Ethernet_Pair1_N), U202.4
/U13A/Ethernet_Pair1_P: U201.4 (Ethernet_Pair1_P), U202.3
/U13A/Ethernet_Pair2_N: U201.9 (Ethernet_Pair2_N), U202.8
/U13A/Ethernet_Pair2_P: U201.11 (Ethernet_Pair2_P), U202.7
/U13A/Ethernet_Pair3_N: U201.5 (Ethernet_Pair3_N), U202.10
/U13A/Ethernet_Pair3_P: U201.3 (Ethernet_Pair3_P), U202.9
/U13A/IMU_I2C7_SCL_M2: U201.80 (SCL0), U203.13 (SCL)
/U13A/IMU_I2C7_SDA_M2: U201.82 (SDA0), U203.14 (SDA)
/U13A/MASKROM_KEY: R202.1, U201.93 (nRPIBOOT)
/U13A/POWER_KEY: U201.99 (Global_EN)
/U13A/RESET: U201.92 (RUN_PG)
Earth: C203.2, U202.15
GND: C201.2, C202.2, C204.2, C205.2, R201.1, SW201.2, U201.1 (GND), U201.2 (GND), U201.7 (GND), U201.8 (GND), U201.13 (GND), U201.14 (GND), U201.22 (GND), U201.23 (GND), U201.32 (GND), U201.33 (GND), U201.42 (GND), U201.43 (GND), U201.52 (GND), U201.53 (GND), U201.59 (GND), U201.60 (GND), U201.65 (GND), U201.66 (GND), U201.71 (GND), U201.74 (GND), U201.98 (GND), U203.1 (SDO/SA0), U203.2 (SDX), U203.3 (SCX), U203.6 (GND), U203.7 (GND); also elsewhere on the board
unnamed: C203.1, R201.2
unnamed: R202.2, SW201.1
UART2_RX_M0: U201.51 (GPIO15); also elsewhere on the board
UART2_TX_M0: U201.55 (GPIO14); also elsewhere on the board

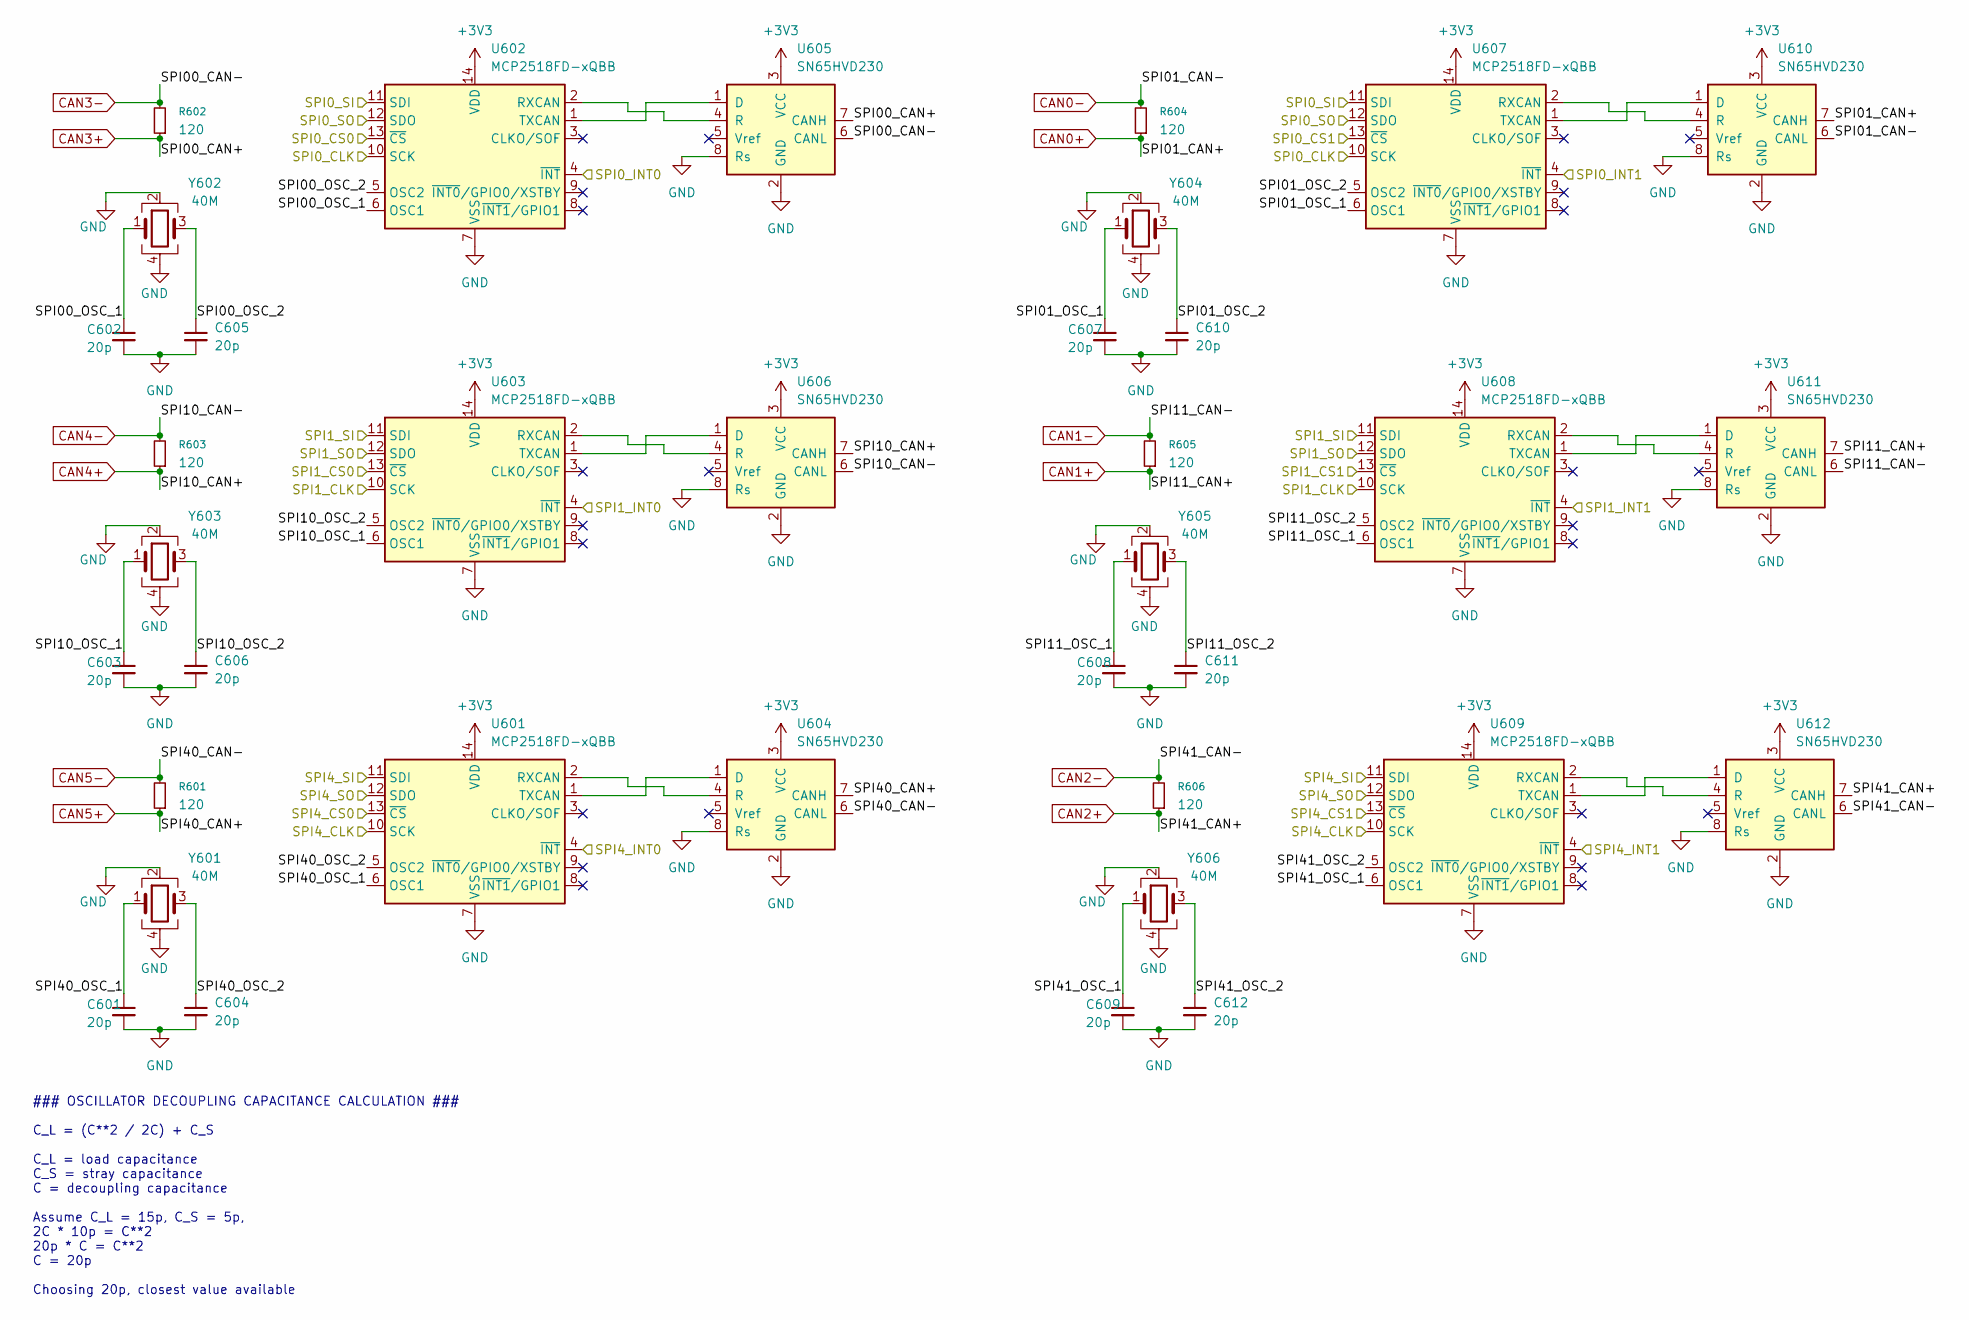
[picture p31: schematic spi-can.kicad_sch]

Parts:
C601, C602, C603, C604, C605, C606, C607, C608, C609, C610, C611, C612: 20p; C_0603_1608Metric; LCSC C165732
R601, R602, R603, R604, R605, R606: 120; R_0402_1005Metric; LCSC C114758
U601, U602, U603, U607, U608, U609: MCP2518FD-xQBB; SOIC-14_3.9x8.7mm_P1.27mm; LCSC C626758
U604, U605, U606, U610, U611, U612: SN65HVD230; SOIC-8_3.9x4.9mm_P1.27mm; LCSC C12084
Y601, Y602, Y603, Y604, Y605, Y606: 40M; Crystal_SMD_3225-4Pin_3.2x2.5mm; LCSC C5444549

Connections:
+3V3: U601.14 (VDD), U602.14 (VDD), U603.14 (VDD), U604.3 (VCC), U605.3 (VCC), U606.3 (VCC), U607.14 (VDD), U608.14 (VDD), U609.14 (VDD), U610.3 (VCC), U611.3 (VCC), U612.3 (VCC); also elsewhere on the board
/J1/SPI1_CS0: U603.13 (~CS); also elsewhere on the board
/J1/SPI1_CS1: U608.13 (~CS); also elsewhere on the board
/J1/SPI1_INT0: U603.4 (~INT); also elsewhere on the board
/J1/SPI1_INT1: U608.4 (~INT); also elsewhere on the board
/J1/SPI4_CS0: U601.13 (~CS); also elsewhere on the board
/J1/SPI4_CS1: U609.13 (~CS); also elsewhere on the board
/J1/SPI4_INT0: U601.4 (~INT); also elsewhere on the board
/J1/SPI4_INT1: U609.4 (~INT); also elsewhere on the board
/SPI-CAN/SPI0_CLK: U602.10 (SCK), U607.10 (SCK); also elsewhere on the board
/SPI-CAN/SPI0_CS0: U602.13 (~CS); also elsewhere on the board
/SPI-CAN/SPI0_CS1: U607.13 (~CS); also elsewhere on the board
/SPI-CAN/SPI0_INT0: U602.4 (~INT); also elsewhere on the board
/SPI-CAN/SPI0_INT1: U607.4 (~INT); also elsewhere on the board
/SPI-CAN/SPI00_OSC_1: C602.1, U602.6 (OSC1), Y602.1
/SPI-CAN/SPI00_OSC_2: C605.1, U602.5 (OSC2), Y602.3
/SPI-CAN/SPI0_SI: U602.11 (SDI), U607.11 (SDI); also elsewhere on the board
/SPI-CAN/SPI0_SO: U602.12 (SDO), U607.12 (SDO); also elsewhere on the board
/SPI-CAN/SPI1_CLK: U603.10 (SCK), U608.10 (SCK); also elsewhere on the board
/SPI-CAN/SPI01_OSC_1: C607.1, U607.6 (OSC1), Y604.1
/SPI-CAN/SPI01_OSC_2: C610.1, U607.5 (OSC2), Y604.3
/SPI-CAN/SPI1_SI: U603.11 (SDI), U608.11 (SDI); also elsewhere on the board
/SPI-CAN/SPI1_SO: U603.12 (SDO), U608.12 (SDO); also elsewhere on the board
/SPI-CAN/SPI4_CLK: U601.10 (SCK), U609.10 (SCK); also elsewhere on the board
/SPI-CAN/SPI4_SI: U601.11 (SDI), U609.11 (SDI); also elsewhere on the board
/SPI-CAN/SPI4_SO: U601.12 (SDO), U609.12 (SDO); also elsewhere on the board
/SPI-CAN/SPI10_OSC_1: C603.1, U603.6 (OSC1), Y603.1
/SPI-CAN/SPI10_OSC_2: C606.1, U603.5 (OSC2), Y603.3
/SPI-CAN/SPI11_OSC_1: C608.1, U608.6 (OSC1), Y605.1
/SPI-CAN/SPI11_OSC_2: C611.1, U608.5 (OSC2), Y605.3
/SPI-CAN/SPI40_OSC_1: C601.1, U601.6 (OSC1), Y601.1
/SPI-CAN/SPI40_OSC_2: C604.1, U601.5 (OSC2), Y601.3
/SPI-CAN/SPI41_OSC_1: C609.1, U609.6 (OSC1), Y606.1
/SPI-CAN/SPI41_OSC_2: C612.1, U609.5 (OSC2), Y606.3
CAN0+: R604.1, U610.7 (CANH); also elsewhere on the board
CAN0-: R604.2, U610.6 (CANL); also elsewhere on the board
CAN1+: R605.1, U611.7 (CANH); also elsewhere on the board
CAN1-: R605.2, U611.6 (CANL); also elsewhere on the board
CAN2+: R606.1, U612.7 (CANH); also elsewhere on the board
CAN2-: R606.2, U612.6 (CANL); also elsewhere on the board
CAN3+: R602.1, U605.7 (CANH); also elsewhere on the board
CAN3-: R602.2, U605.6 (CANL); also elsewhere on the board
CAN4+: R603.1, U606.7 (CANH); also elsewhere on the board
CAN4-: R603.2, U606.6 (CANL); also elsewhere on the board
CAN5+: R601.1, U604.7 (CANH); also elsewhere on the board
CAN5-: R601.2, U604.6 (CANL); also elsewhere on the board
GND: C601.2, C602.2, C603.2, C604.2, C605.2, C606.2, C607.2, C608.2, C609.2, C610.2, C611.2, C612.2, U601.7 (VSS), U601.15 (VSS), U602.7 (VSS), U602.15 (VSS), U603.7 (VSS), U603.15 (VSS), U604.2 (GND), U604.8 (Rs), U605.2 (GND), U605.8 (Rs), U606.2 (GND), U606.8 (Rs), U607.7 (VSS), U607.15 (VSS), U608.7 (VSS), U608.15 (VSS), U609.7 (VSS), U609.15 (VSS), U610.2 (GND), U610.8 (Rs), U611.2 (GND), U611.8 (Rs), U612.2 (GND), U612.8 (Rs), Y601.2, Y601.4, Y602.2, Y602.4, Y603.2, Y603.4, Y604.2, Y604.4, Y605.2, Y605.4, Y606.2, Y606.4; also elsewhere on the board
unnamed: U601.2 (RXCAN), U604.4 (R)
unnamed: U601.1 (TXCAN), U604.1 (D)
unnamed: U602.2 (RXCAN), U605.4 (R)
unnamed: U602.1 (TXCAN), U605.1 (D)
unnamed: U603.2 (RXCAN), U606.4 (R)
unnamed: U603.1 (TXCAN), U606.1 (D)
unnamed: U607.2 (RXCAN), U610.4 (R)
unnamed: U607.1 (TXCAN), U610.1 (D)
unnamed: U608.2 (RXCAN), U611.4 (R)
unnamed: U608.1 (TXCAN), U611.1 (D)
unnamed: U609.2 (RXCAN), U612.4 (R)
unnamed: U609.1 (TXCAN), U612.1 (D)

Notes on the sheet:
### OSCILLATOR DECOUPLING CAPACITANCE CALCULATION ### C_L = (C**2 / 2C) + C_S C_L = load capacitance C_S = stray capacitance C = decoupling capacitance Assume C_L = 15p, C_S = 5p, 2C * 10p = C**2 20p * C = C**2 C = 20p Choosing 20p, closest value available

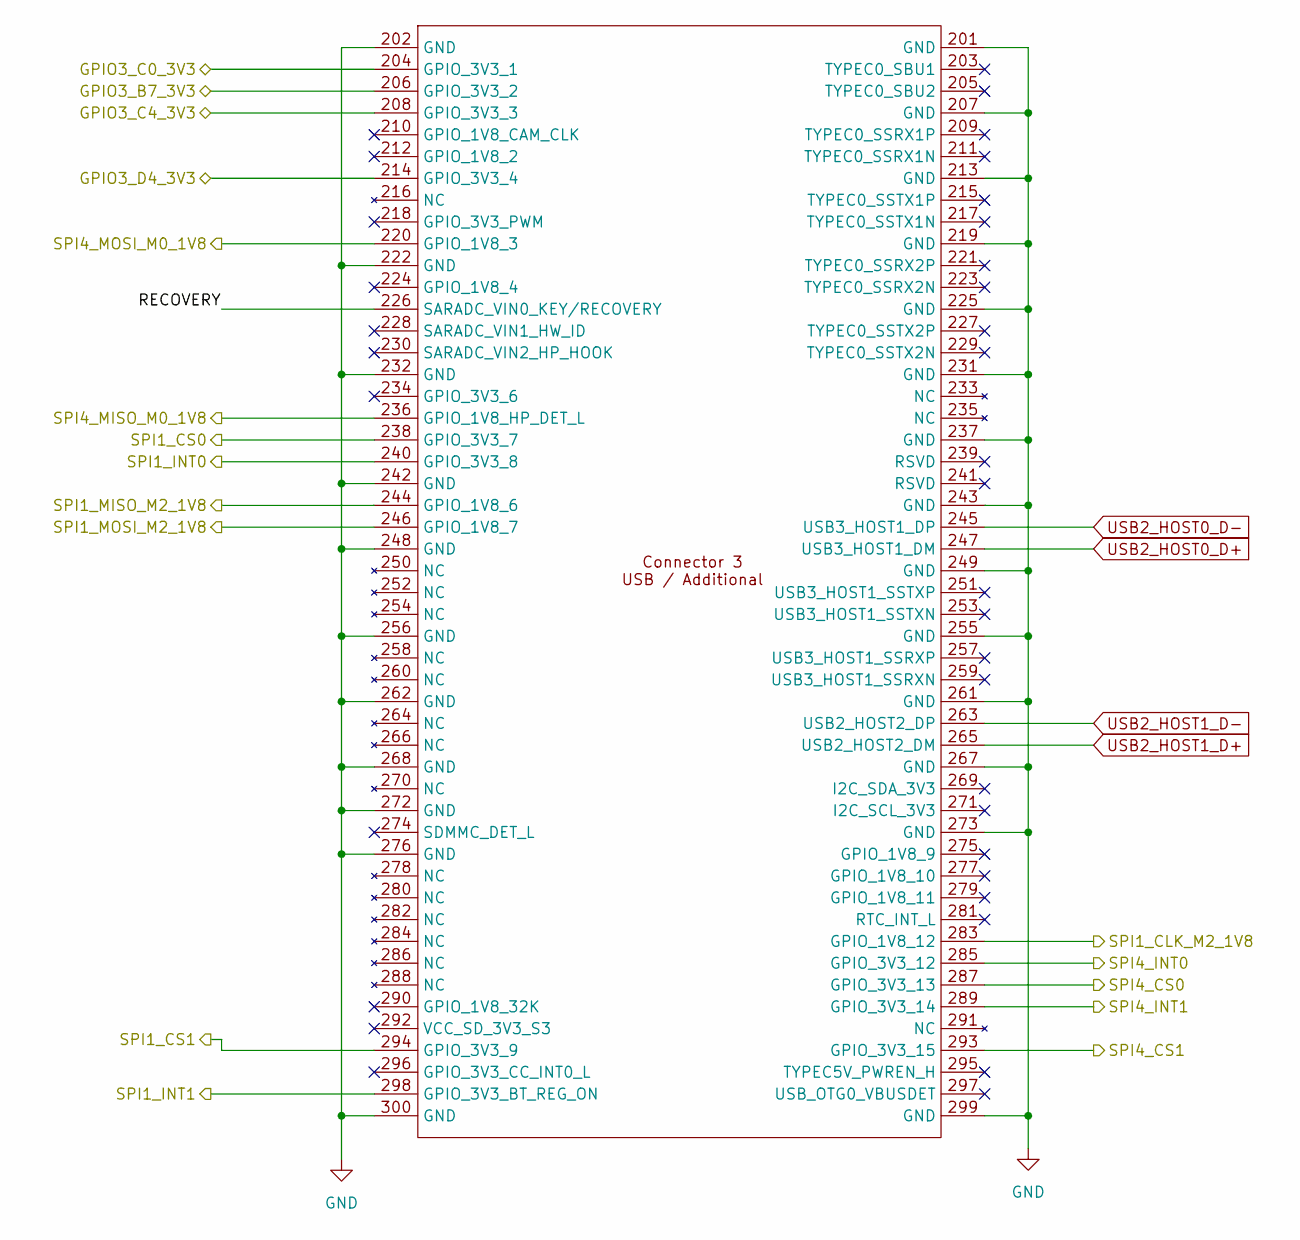
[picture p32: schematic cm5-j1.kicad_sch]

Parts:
U401: Hirose DF40C-100DS-0.4V; radxa_cm5_3; LCSC C597931

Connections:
/J1/GPIO3_B7_3V3: U401.206 (GPIO_3V3_2); also elsewhere on the board
/J1/GPIO3_C0_3V3: U401.204 (GPIO_3V3_1); also elsewhere on the board
/J1/GPIO3_C4_3V3: U401.208 (GPIO_3V3_3); also elsewhere on the board
/J1/GPIO3_D4_3V3: U401.214 (GPIO_3V3_4); also elsewhere on the board
/J1/RECOVERY: U401.226 (SARADC_VIN0_KEY/RECOVERY)
/J1/SPI1_CLK_M2_1V8: U401.283 (GPIO_1V8_12); also elsewhere on the board
/J1/SPI1_CS0: U401.238 (GPIO_3V3_7); also elsewhere on the board
/J1/SPI1_CS1: U401.294 (GPIO_3V3_9); also elsewhere on the board
/J1/SPI1_INT0: U401.240 (GPIO_3V3_8); also elsewhere on the board
/J1/SPI1_INT1: U401.298 (GPIO_3V3_BT_REG_ON); also elsewhere on the board
/J1/SPI1_MISO_M2_1V8: U401.244 (GPIO_1V8_6); also elsewhere on the board
/J1/SPI1_MOSI_M2_1V8: U401.246 (GPIO_1V8_7); also elsewhere on the board
/J1/SPI4_CS0: U401.287 (GPIO_3V3_13); also elsewhere on the board
/J1/SPI4_CS1: U401.293 (GPIO_3V3_15); also elsewhere on the board
/J1/SPI4_INT0: U401.285 (GPIO_3V3_12); also elsewhere on the board
/J1/SPI4_INT1: U401.289 (GPIO_3V3_14); also elsewhere on the board
/J1/SPI4_MISO_M0_1V8: U401.236 (GPIO_1V8_HP_DET_L); also elsewhere on the board
/J1/SPI4_MOSI_M0_1V8: U401.220 (GPIO_1V8_3); also elsewhere on the board
GND: U401.201 (GND), U401.202 (GND), U401.207 (GND), U401.213 (GND), U401.219 (GND), U401.222 (GND), U401.225 (GND), U401.231 (GND), U401.232 (GND), U401.237 (GND), U401.242 (GND), U401.243 (GND), U401.248 (GND), U401.249 (GND), U401.255 (GND), U401.256 (GND), U401.261 (GND), U401.262 (GND), U401.267 (GND), U401.268 (GND), U401.272 (GND), U401.273 (GND), U401.276 (GND), U401.299 (GND), U401.300 (GND); also elsewhere on the board
USB2_HOST0_D+: U401.247 (USB3_HOST1_DM); also elsewhere on the board
USB2_HOST0_D-: U401.245 (USB3_HOST1_DP); also elsewhere on the board
USB2_HOST1_D+: U401.265 (USB2_HOST2_DM); also elsewhere on the board
USB2_HOST1_D-: U401.263 (USB2_HOST2_DP); also elsewhere on the board

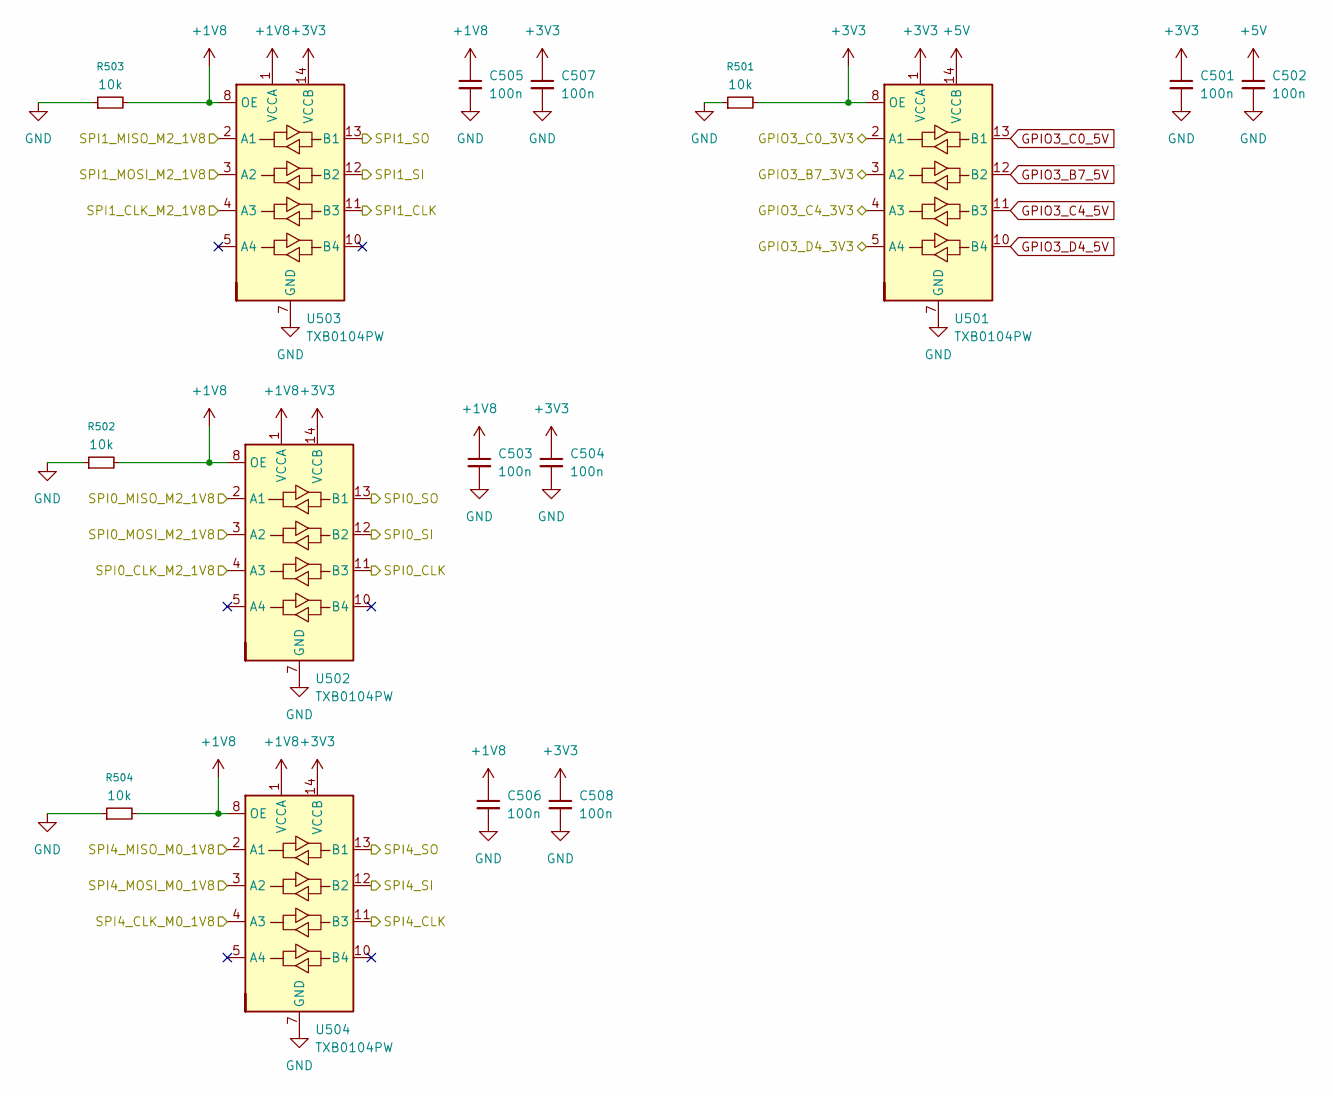
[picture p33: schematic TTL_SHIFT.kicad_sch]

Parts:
C501, C502, C503, C504, C505, C506, C507, C508: 100n; C_0402_1005Metric; LCSC C77020
R501, R502, R503, R504: 10k; R_0402_1005Metric; LCSC C190095
U501, U502, U503, U504: TXB0104PW; TSSOP-14_4.4x5mm_P0.65mm; LCSC C60708

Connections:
+1V8: C503.1, C505.1, C506.1, R502.2, R503.2, R504.2, U502.1 (VCCA), U502.8 (OE), U503.1 (VCCA), U503.8 (OE), U504.1 (VCCA), U504.8 (OE); also elsewhere on the board
+3V3: C501.1, C504.1, C507.1, C508.1, R501.2, U501.1 (VCCA), U501.8 (OE), U502.14 (VCCB), U503.14 (VCCB), U504.14 (VCCB); also elsewhere on the board
+5V: C502.1, U501.14 (VCCB); also elsewhere on the board
/J1/GPIO3_B7_3V3: U501.3 (A2); also elsewhere on the board
/J1/GPIO3_C0_3V3: U501.2 (A1); also elsewhere on the board
/J1/GPIO3_C4_3V3: U501.4 (A3); also elsewhere on the board
/J1/GPIO3_D4_3V3: U501.5 (A4); also elsewhere on the board
/J1/SPI1_CLK_M2_1V8: U503.4 (A3); also elsewhere on the board
/J1/SPI1_MISO_M2_1V8: U503.2 (A1); also elsewhere on the board
/J1/SPI1_MOSI_M2_1V8: U503.3 (A2); also elsewhere on the board
/J1/SPI4_MISO_M0_1V8: U504.2 (A1); also elsewhere on the board
/J1/SPI4_MOSI_M0_1V8: U504.3 (A2); also elsewhere on the board
/SPI-CAN/SPI0_CLK: U502.11 (B3); also elsewhere on the board
/SPI-CAN/SPI0_SI: U502.12 (B2); also elsewhere on the board
/SPI-CAN/SPI0_SO: U502.13 (B1); also elsewhere on the board
/SPI-CAN/SPI1_CLK: U503.11 (B3); also elsewhere on the board
/SPI-CAN/SPI1_SI: U503.12 (B2); also elsewhere on the board
/SPI-CAN/SPI1_SO: U503.13 (B1); also elsewhere on the board
/SPI-CAN/SPI4_CLK: U504.11 (B3); also elsewhere on the board
/SPI-CAN/SPI4_SI: U504.12 (B2); also elsewhere on the board
/SPI-CAN/SPI4_SO: U504.13 (B1); also elsewhere on the board
/TTL-SHIFT/SPI0_CLK_M2_1V8: U502.4 (A3); also elsewhere on the board
/TTL-SHIFT/SPI0_MISO_M2_1V8: U502.2 (A1); also elsewhere on the board
/TTL-SHIFT/SPI0_MOSI_M2_1V8: U502.3 (A2); also elsewhere on the board
/TTL-SHIFT/SPI4_CLK_M0_1V8: U504.4 (A3); also elsewhere on the board
GND: C501.2, C502.2, C503.2, C504.2, C505.2, C506.2, C507.2, C508.2, R501.1, R502.1, R503.1, R504.1, U501.7 (GND), U502.7 (GND), U503.7 (GND), U504.7 (GND); also elsewhere on the board
GPIO3_B7_5V: U501.12 (B2); also elsewhere on the board
GPIO3_C0_5V: U501.13 (B1); also elsewhere on the board
GPIO3_C4_5V: U501.11 (B3); also elsewhere on the board
GPIO3_D4_5V: U501.10 (B4); also elsewhere on the board

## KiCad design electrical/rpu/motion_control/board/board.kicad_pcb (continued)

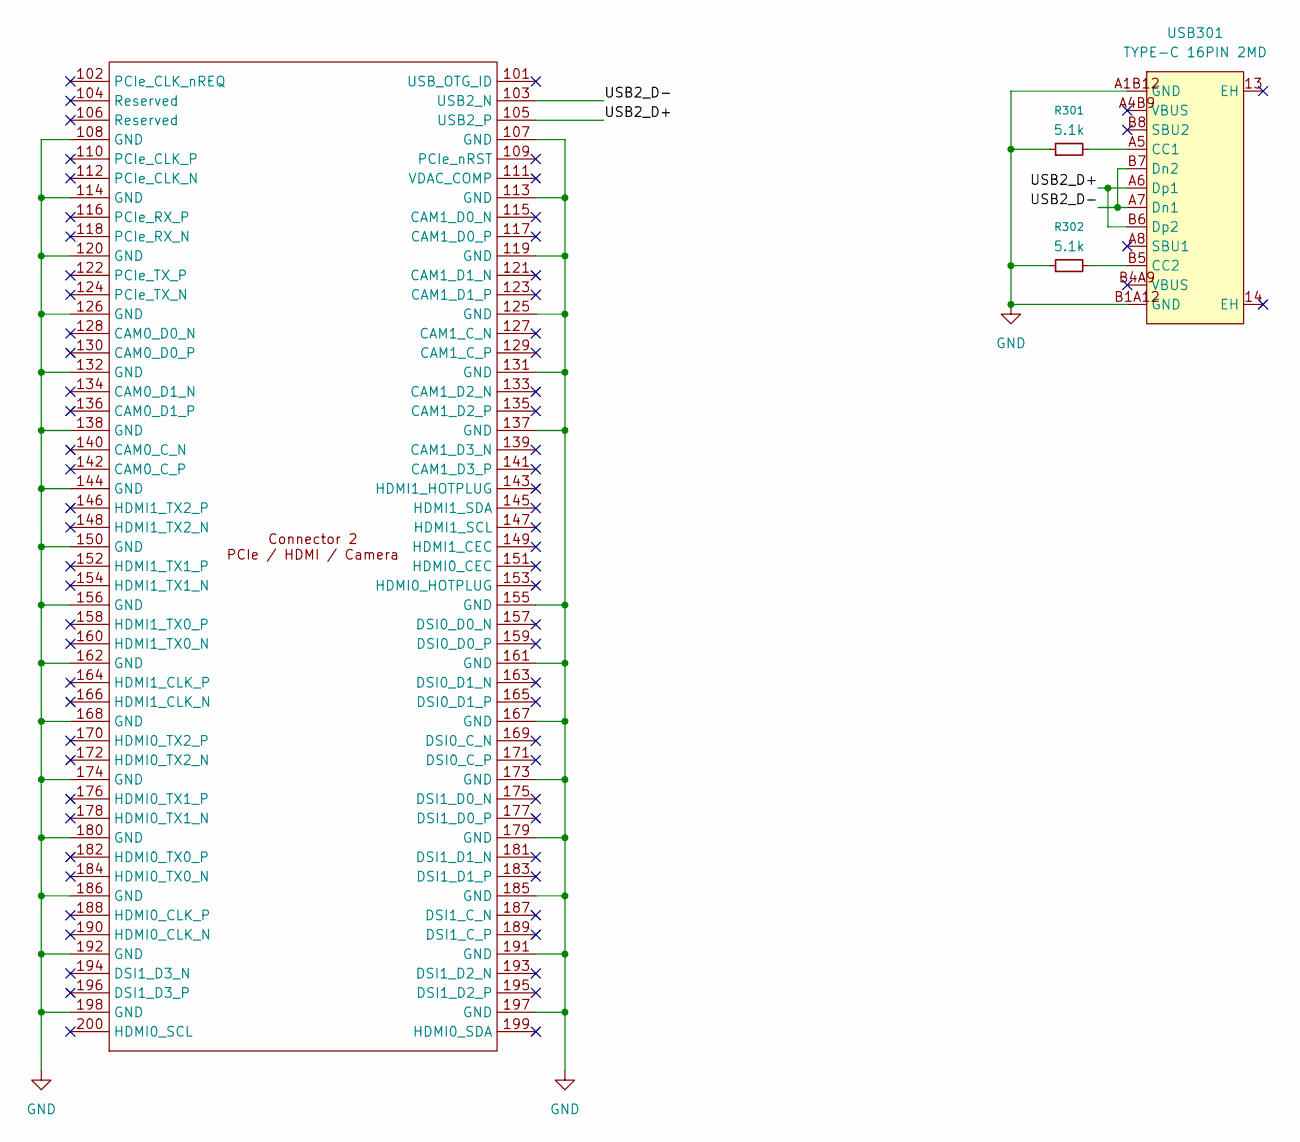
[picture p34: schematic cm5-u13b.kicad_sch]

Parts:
R301, R302: 5.1k; R_0402_1005Metric; LCSC C105872
U301: Hirose DF40C-100DS-0.4V; radxa_cm5_2; LCSC C597931
USB301: TYPE-C 16PIN 2MD; USB-C-SMD_TYPE-C-16PIN-2MD-073; MPN TYPE-C 16PIN 2MD(073); LCSC Part C2765186

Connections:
/U13B/USB2_D+: U301.105 (USB2_P), USB301.A6 (Dp1), USB301.B6 (Dp2)
/U13B/USB2_D-: U301.103 (USB2_N), USB301.A7 (Dn1), USB301.B7 (Dn2)
GND: R301.1, R302.1, U301.107 (GND), U301.108 (GND), U301.113 (GND), U301.114 (GND), U301.119 (GND), U301.120 (GND), U301.125 (GND), U301.126 (GND), U301.131 (GND), U301.132 (GND), U301.137 (GND), U301.138 (GND), U301.144 (GND), U301.150 (GND), U301.155 (GND), U301.156 (GND), U301.161 (GND), U301.162 (GND), U301.167 (GND), U301.168 (GND), U301.173 (GND), U301.174 (GND), U301.179 (GND), U301.180 (GND), U301.185 (GND), U301.186 (GND), U301.191 (GND), U301.192 (GND), U301.197 (GND), U301.198 (GND), USB301.A1B12 (GND), USB301.B1A12 (GND); also elsewhere on the board
unnamed: R301.2, USB301.A5 (CC1)
unnamed: R302.2, USB301.B5 (CC2)

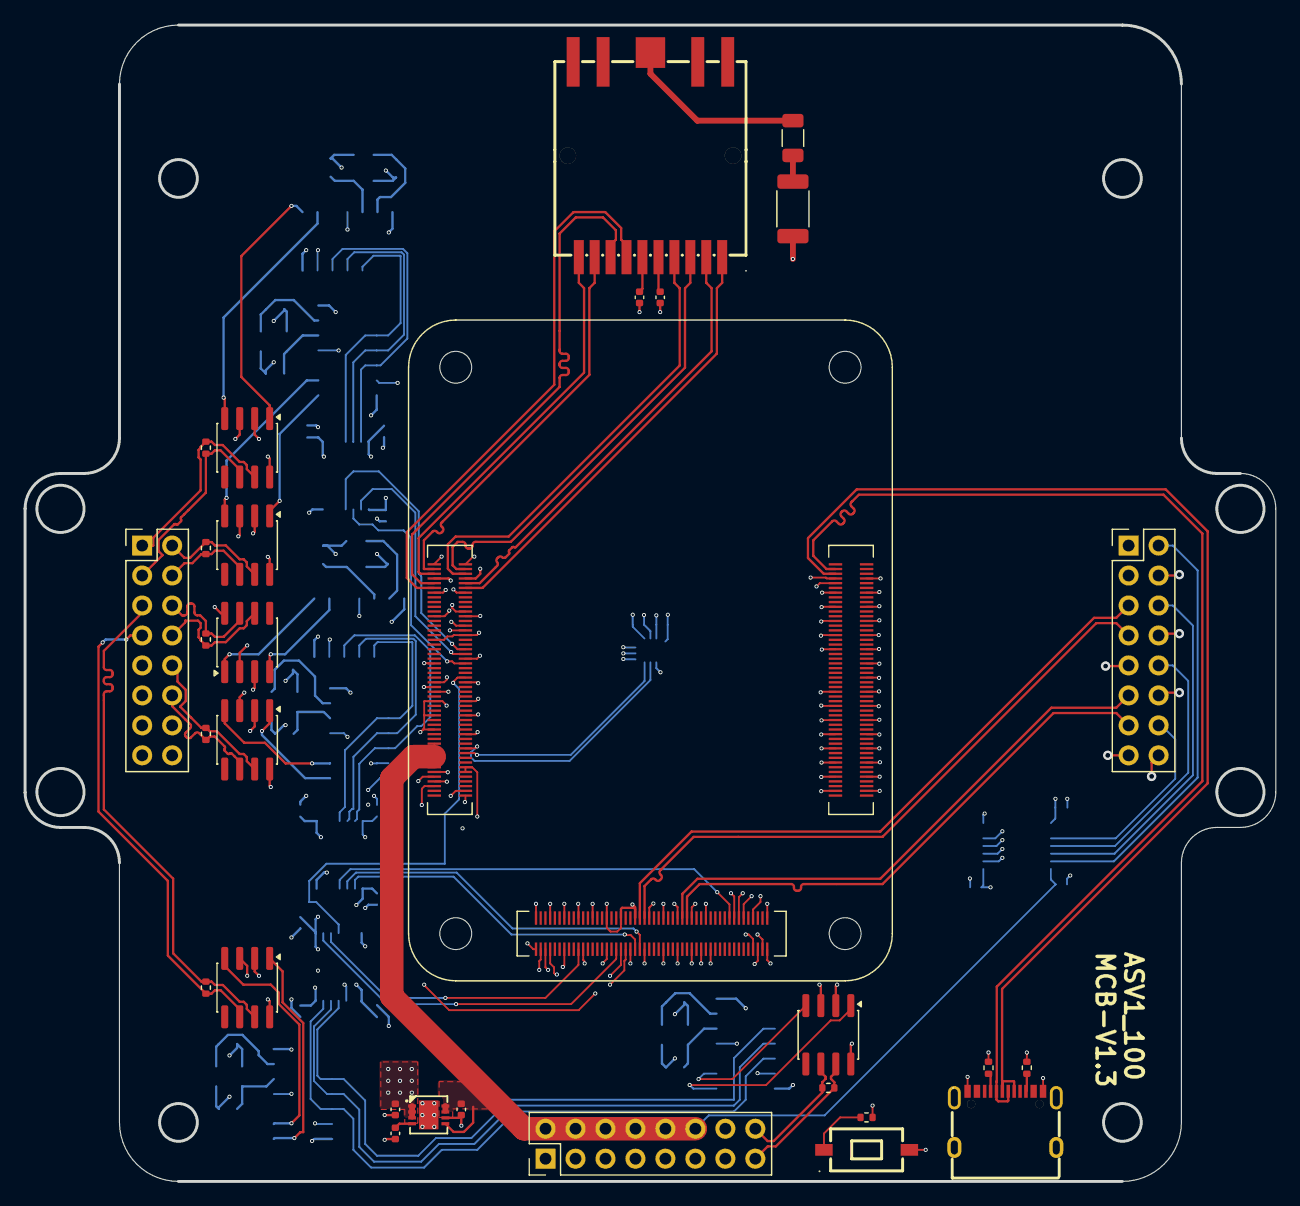
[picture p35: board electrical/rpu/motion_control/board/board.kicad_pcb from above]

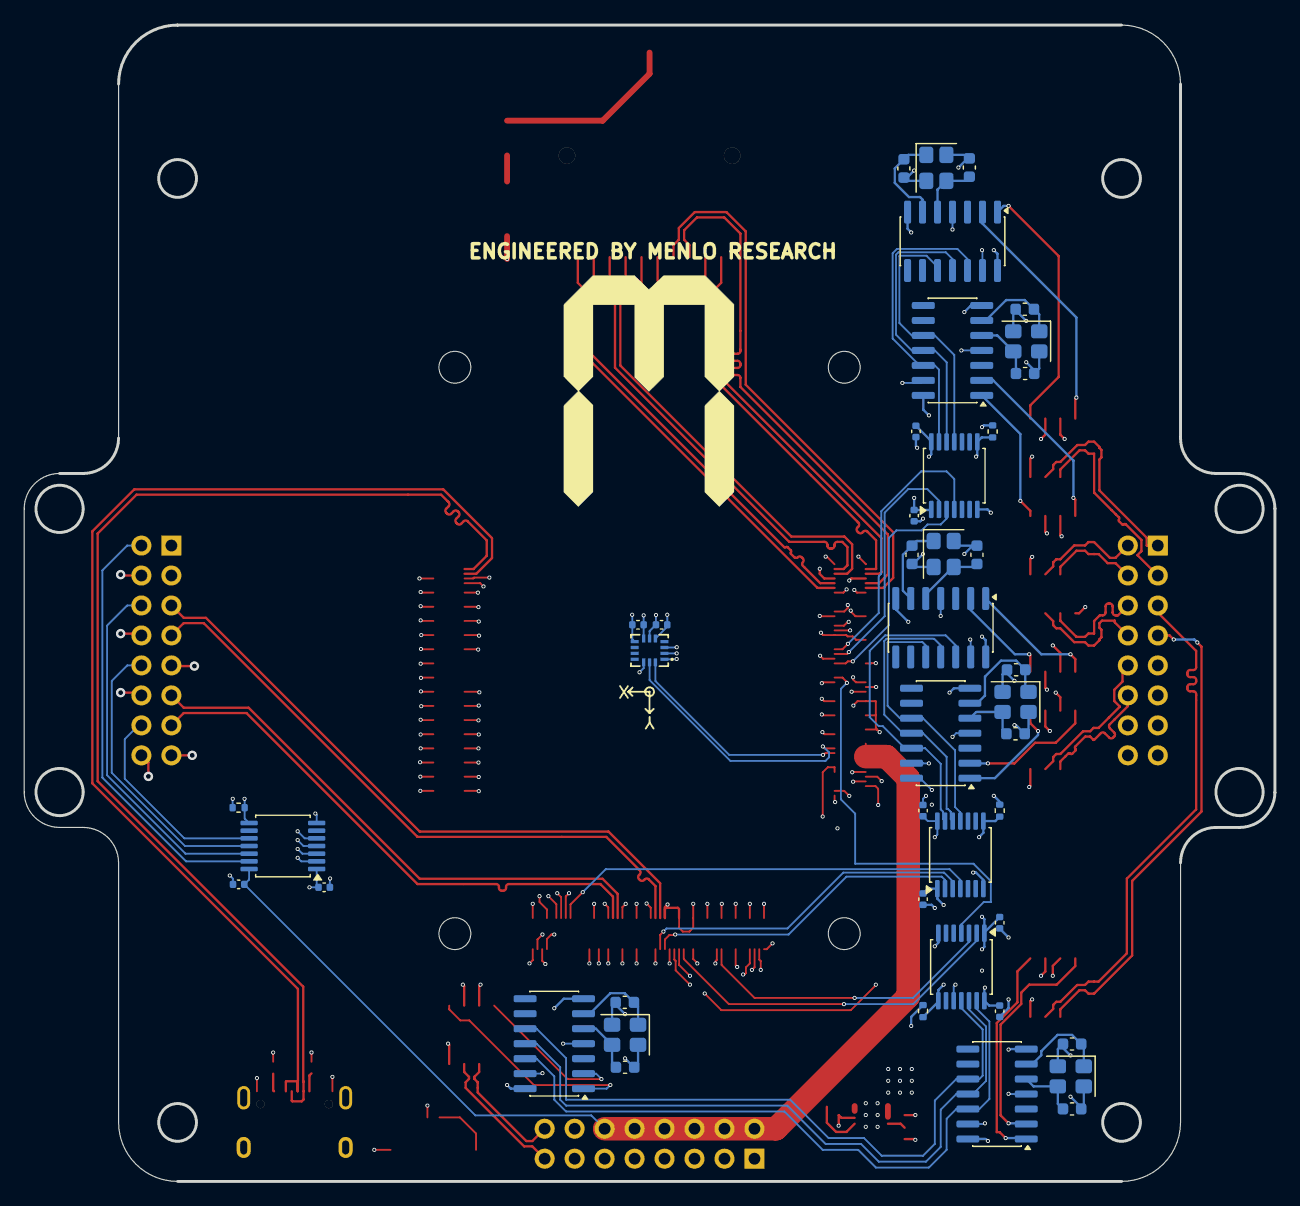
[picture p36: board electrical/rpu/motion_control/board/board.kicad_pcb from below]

Board: 4 copper layers, 106.0 x 98.0 mm, 75 parts (43 on the bottom side), 105 nets.

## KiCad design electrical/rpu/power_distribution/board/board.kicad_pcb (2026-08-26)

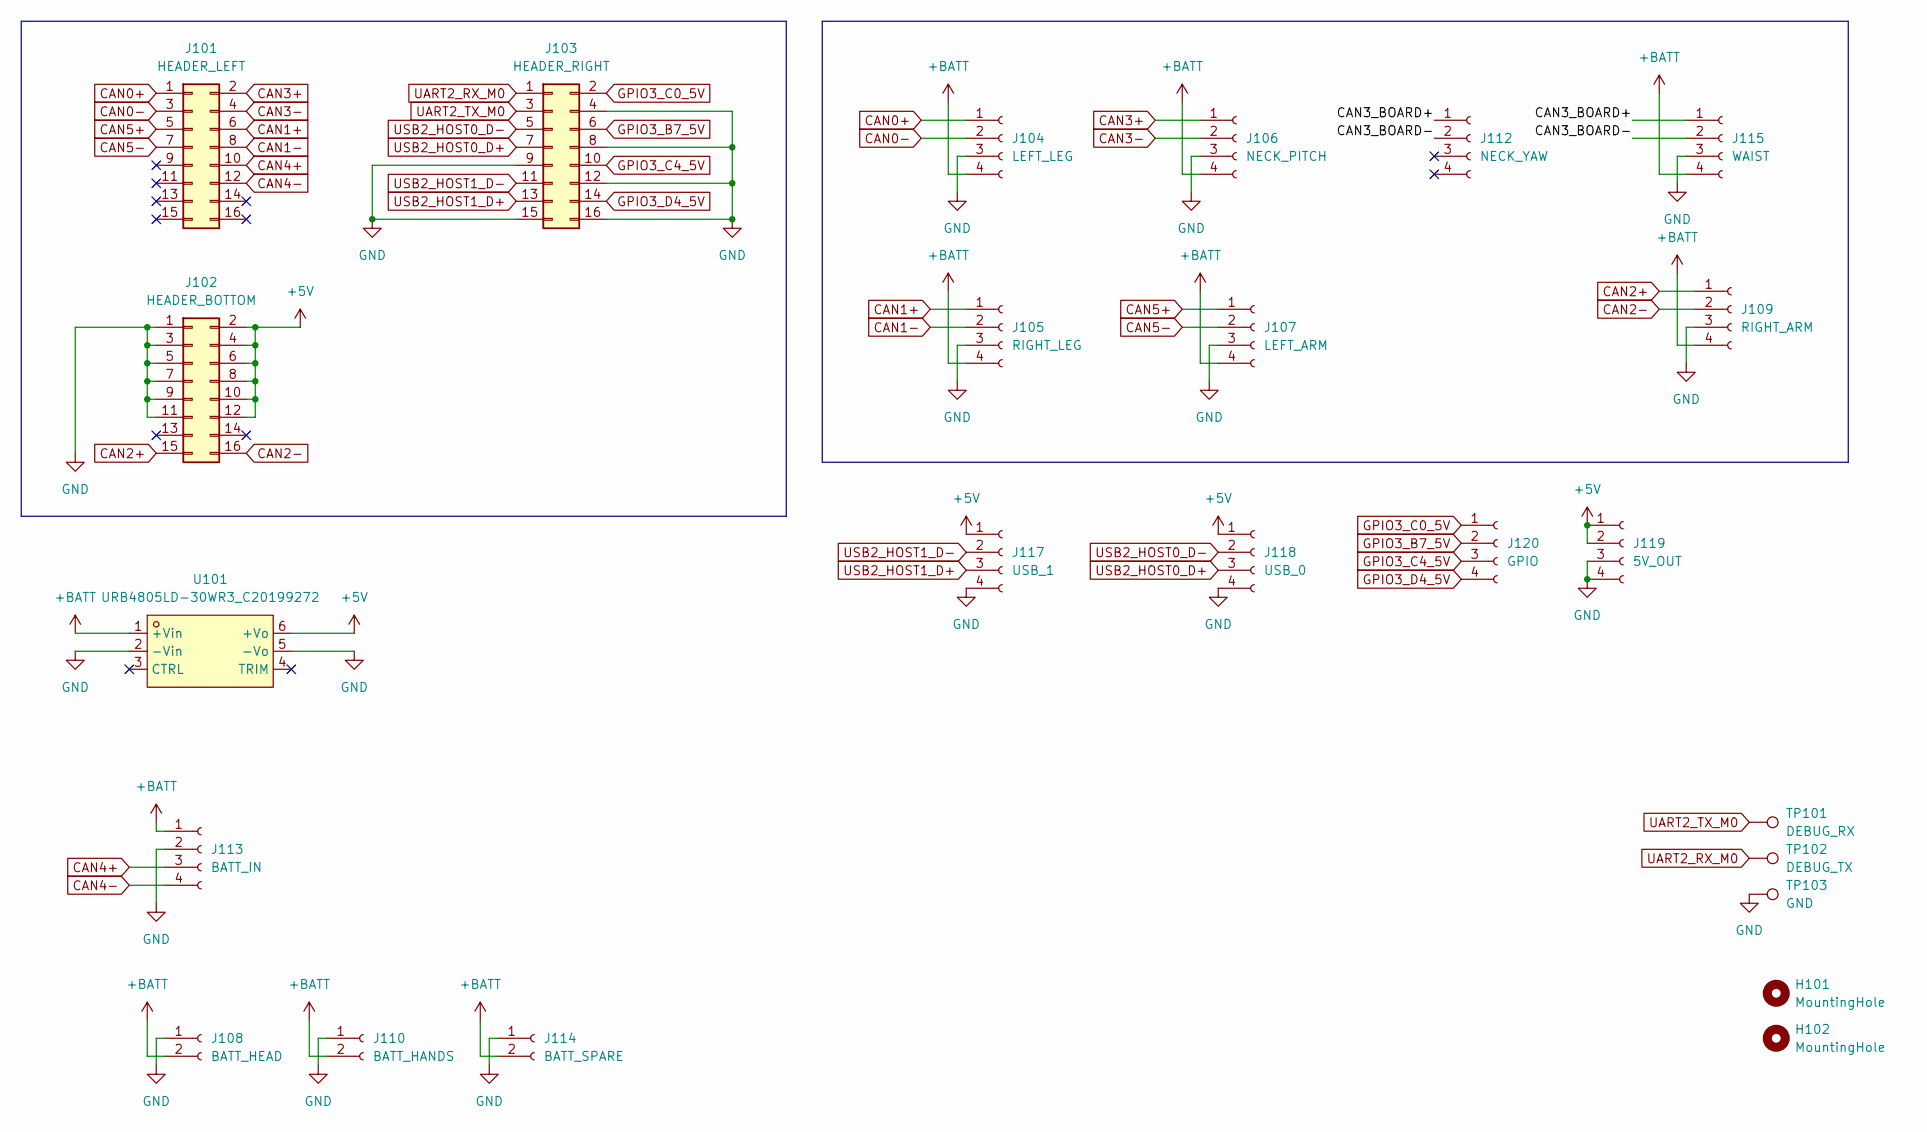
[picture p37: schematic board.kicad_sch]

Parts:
H101, H102: MountingHole; MountingHole_3.2mm_M3
J101: HEADER_LEFT; PinSocket_2x08_P2.54mm_Vertical; LCSC C30734
J102: HEADER_BOTTOM; PinSocket_2x08_P2.54mm_Vertical; LCSC C30734
J103: HEADER_RIGHT; PinSocket_2x08_P2.54mm_Vertical; LCSC C30734
J104: LEFT_LEG; CONN-TH_XT30PB-M
J105: RIGHT_LEG; CONN-TH_XT30PB-M
J106: NECK_PITCH; CONN-TH_XT30PB-M
J107: LEFT_ARM; CONN-TH_XT30PB-M
J108: BATT_HEAD; AMASS_XT30UPB-F_1x02_P5.0mm_Vertical; LCSC C108769
J109: RIGHT_ARM; CONN-TH_XT30PB-M
J110: BATT_HANDS; AMASS_XT30UPB-F_1x02_P5.0mm_Vertical; LCSC C108769
J112: NECK_YAW; CONN-TH_XT30PB-M
J113: BATT_IN; CONN-SMD_XT90-2-2-PB-MGY; LCSC C19268046
J114: BATT_SPARE; AMASS_XT30UPB-F_1x02_P5.0mm_Vertical; LCSC C108769
J115: WAIST; CONN-TH_XT30PB-M
J117: USB_1; JST_XH_B4B-XH-A_1x04_P2.50mm_Vertical; LCSC C144395
J118: USB_0; JST_XH_B4B-XH-A_1x04_P2.50mm_Vertical; LCSC C144395
J119: 5V_OUT; JST_XH_B4B-XH-A_1x04_P2.50mm_Vertical; LCSC C144395
J120: GPIO; JST_XH_B4B-XH-A_1x04_P2.50mm_Vertical; LCSC C144395
TP101: DEBUG_RX; TestPoint_Pad_D1.0mm
TP102: DEBUG_TX; TestPoint_Pad_D1.0mm
TP103: GND; TestPoint_Pad_D1.0mm
U101: URB4805LD-30WR3_C20199272; PWRM-TH_TURBXXXXLD-30WR3; MPN URB4805LD-30WR3; LCSC Part C20199272

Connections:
+5V: J102.2, J102.4, J102.6, J102.8, J102.10, J102.12, J117.1, J118.1, J119.1, J119.2, U101.6 (+Vo)
+BATT: J104.4, J105.4, J106.4, J107.4, J108.2, J109.4, J110.2, J113.1, J114.2, J115.4, U101.1 (+Vin)
/CAN3_BOARD+: J112.1, J115.1
/CAN3_BOARD-: J112.2, J115.2
CAN0+: J101.1, J104.1
CAN0-: J101.3, J104.2
CAN1+: J101.6, J105.1
CAN1-: J101.8, J105.2
CAN2+: J102.15, J109.1
CAN2-: J102.16, J109.2
CAN3+: J101.2, J106.1
CAN3-: J101.4, J106.2
CAN4+: J101.10, J113.3
CAN4-: J101.12, J113.4
CAN5+: J101.5, J107.1
CAN5-: J101.7, J107.2
GND: J102.1, J102.3, J102.5, J102.7, J102.9, J102.11, J103.4, J103.8, J103.9, J103.12, J103.15, J103.16, J104.3, J105.3, J106.3, J107.3, J108.1, J109.3, J110.1, J113.2, J114.1, J115.3, J117.4, J118.4, J119.3, J119.4, TP103.1 (1_1), U101.2 (-Vin), U101.5 (-Vo)
GPIO3_B7_5V: J103.6, J120.2
GPIO3_C0_5V: J103.2, J120.1
GPIO3_C4_5V: J103.10, J120.3
GPIO3_D4_5V: J103.14, J120.4
UART2_RX_M0: J103.1, TP102.1 (1_1)
UART2_TX_M0: J103.3, TP101.1 (1_1)
USB2_HOST0_D+: J103.7, J118.3
USB2_HOST0_D-: J103.5, J118.2
USB2_HOST1_D+: J103.13, J117.3
USB2_HOST1_D-: J103.11, J117.2

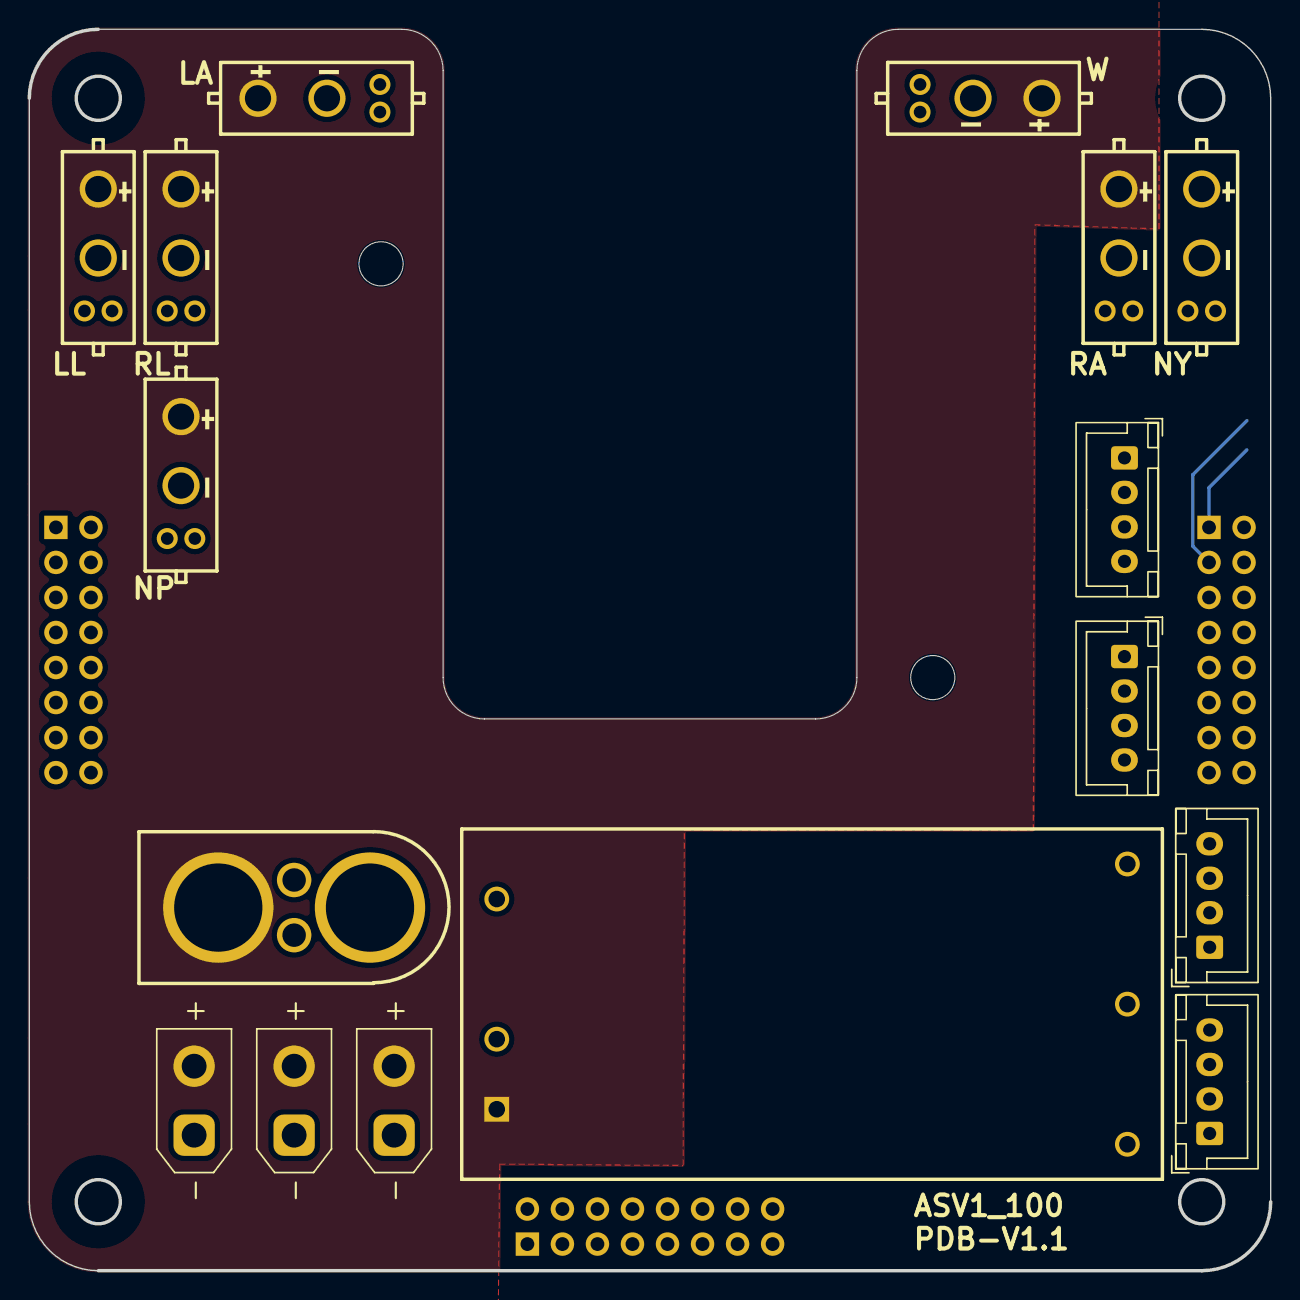
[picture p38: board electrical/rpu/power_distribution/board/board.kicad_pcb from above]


Board: 4 copper layers, 90.0 x 90.0 mm, 24 parts (6 on the bottom side), 27 nets.

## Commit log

2026-08-13 Update sim-model with latest meshes, add URDF
    [ANKLE_B_NEW.STL, LEFT_ANKLE_B.STL, LEFT_TOE.STL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]
2026-08-21 Asimov v1 Upgrades
    [ASIMOV_V1.STEP, ASV1_100.STEP, ASV1_100_04C.STEP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]
2026-08-26 updating source files, touching up READMEs
    [TTL_SHIFT.kicad_sch, board.kicad_pcb, board.kicad_sch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]
2026-08-31 add wiring
    [misc-wires.csv, motor-wires.csv]
2026-09-14 media hat power fix fabrication ready
    [board.kicad_pcb, board.kicad_sch]
2026-09-21 fix STEP path
    [board.kicad_pcb]
2026-09-23 flip connector polarity
    [board.kicad_pcb, board.kicad_sch]
2026-09-23 change FLT to RED LED
    [board.kicad_pcb, board.kicad_sch]
2026-09-24 LCSC number fix
    [board.kicad_pcb]
2026-10-30 media hat power fix fabrication ready (#22)
    * media hat power fix fabrication ready
    * fix STEP path
    * flip connector polarity
    * change FLT to RED LED
    * LCSC number fix
2026-11-04 Add shoes, dummy hands, and stool fabrication assets (#31)
    * Add TPU shoe soles and stool fabrication assets
    * Document confirmed shoe and stool fabrication settings
    * Move shoes to accessories and add dummy hands print project

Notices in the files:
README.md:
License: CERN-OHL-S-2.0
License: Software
